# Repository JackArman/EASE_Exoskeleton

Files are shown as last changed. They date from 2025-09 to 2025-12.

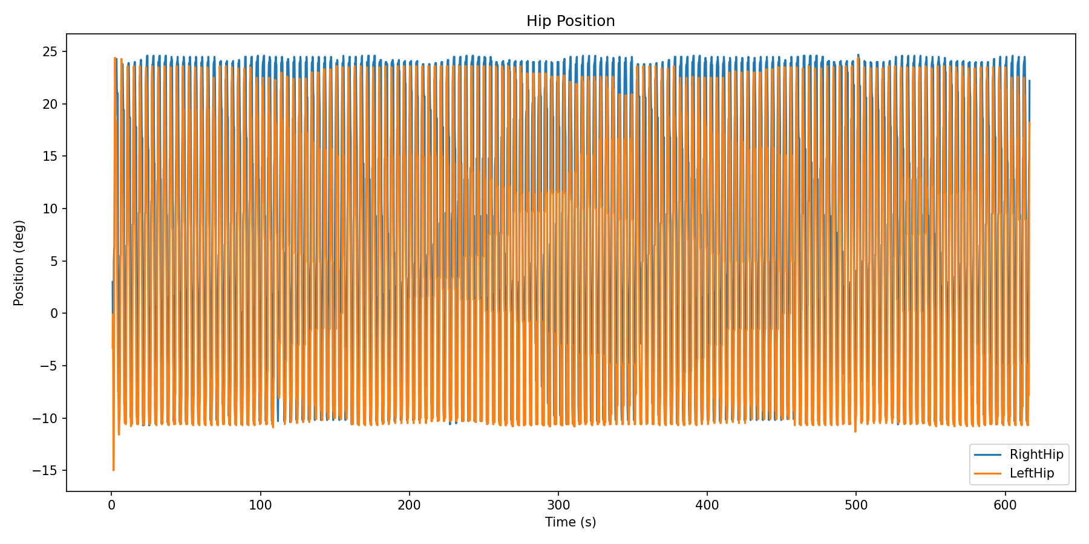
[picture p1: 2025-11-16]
Power Systems/Experiment Reults/ExperimentTest/Hip_PositionDeg.png

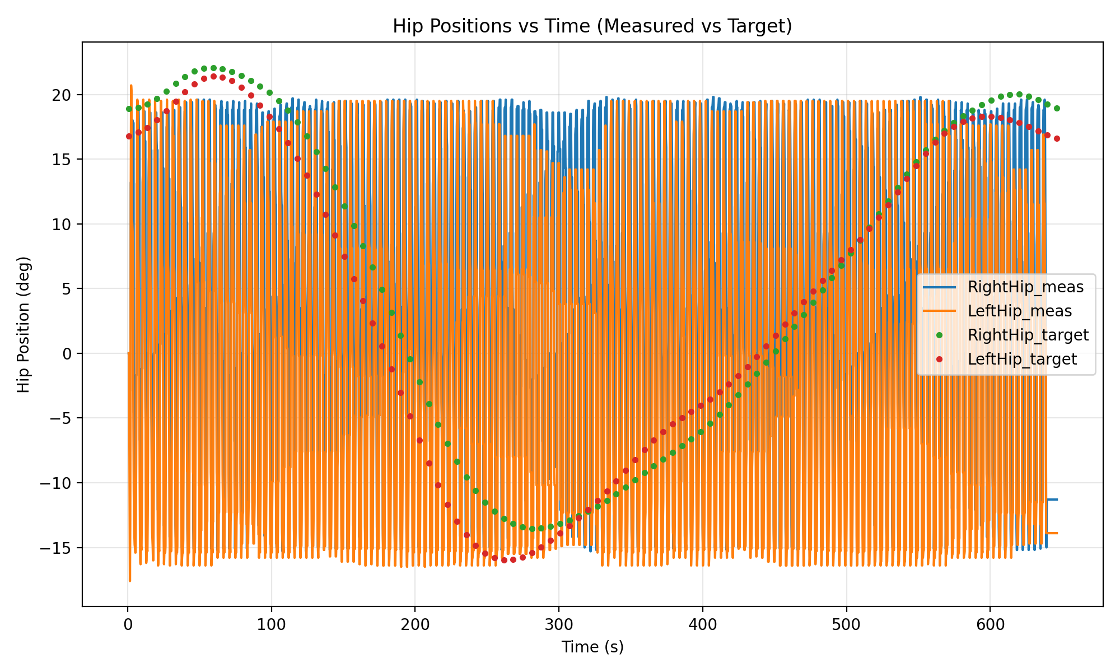
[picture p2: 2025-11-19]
Power Systems/Experiment Reults/hip_positions_with_targets.png

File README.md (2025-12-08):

# EASE – Exoskeleton for Assistive Support of Elderlies

EASE is a modular, lightweight, and energy-efficient lower-limb exoskeleton designed to support mobility in elderly individuals. This repository contains resources for the development, control, simulation, and power management systems of the EASE exoskeleton.

---

## Repository Structure
PowerSystems/ # Battery, buck converters, energy management
ControlSystems/ # Gait detection, motor control, safety features
Simulation/ # Gait cycle simulations and performance modeling
Docs/ # Literature review, diagrams, system design documents
SharedAssets/ # CAD files, visuals, datasheets

---

## Features

- Real-time energy management and fault detection
- Modular 3D-printed design for low cost and ease of maintenance
- Adaptive control strategies for various gait patterns
- Support for simulation and hardware-in-the-loop testing

---

## Related Resources

- [Google Drive Folder](https://drive.google.com/drive/folders/12fcUsN3FNqKwQU3XB_L2-6pgEOXsACwc?usp=sharing)
- [Quantitative Data](https://unsw.sharepoint.com/:x:/r/sites/EASEExoskeletonforAssistiveSupportofElderlies/_layouts/15/Doc2.aspx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)
- [Safe Work Procedure](https://salus.unsw.edu.au/unsw/#/view/Published-Safe-Work-Procedure/SWP-0009450) 
---

## Documentation

Refer to the [`Docs/`](./Docs/) folder for:
- System architecture diagrams
- Literature reviews
- Regulatory considerations
- Evaluation methodology

### Control Systems Documentation

Refer to the README.md within [Control System/README.md](Control%20System/README.md)

### Mechanical Systems Documentation

Refer to the README.md within [Mechanical System/README.md](Mechanical%20System/README.md)

---

## Contributors

- Power Systems Team
- Control Systems Team
- Simulation & Modelling Team

---

## License

This project is licensed under the UNSW License.

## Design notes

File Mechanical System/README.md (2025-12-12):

# EASE Exoskeleton – Mechanical System
The Mechanical System can be further divided into the **Exoskeleton's Docking Station** and **Exoskeleton's Back and Arm rests**. The docking station was made on Fusion360 whilst (majority of) the back and arm rest was made on Solidworks.

## ⚙ Docking Station
### Description
The docking station consists of 3D printed parts custom-designed to the current backrest and is held by a frame made out of 40 x 40 20 series V-slot extrusions. It is design for easy use so the elderly walks forwards into it.
Please see the video to demonstrate how it works.

The following is a list of all files and descriptions:

`ASSEMBLY - Full Assembly` - This is an full exoskeleton assembly with the original leg assembly but uses an outdated back and arm rest assembly.

`Armrest motor mount` - The current adaptor between the original leg design and the arm rests, however, this has been prone to shearing at a 15% infill.

`Docking Station Assembly` - A one sided assembly of the Docking Station showing the location of armrest, hinge, stopping mechanism and shape of frame.

`Docking Station Arm` - Arms that extend from the under the armrest to the backrest to support the backrest weight and ensure the exoskeleton's U-joint does not rotate and cause the exoskeleton to fall off. Has a section cut off from it for the weight based locking mechanism. 
Two springs are to be situate in the small circle cut outs and when exoskeleton rest upon it, the piece's extrusion at the bottom hits the stopper, preventing the hinge to return to its original position.

`Ramp fitting` - Ramp to stop the hinge from overturning.

`Returning Hinge` - Inaccurate CAD of TruClose® Self-Closing Pool Gate Safety Hinges but with joint added for demonstration.

`Spring Stopper` - Attachment to pole that works with the spring system on the `Docking Station Arm`s to stop the hinge from returning when exoskeleton is on it.

`Vslot Corner joint` - The joint that is used to construct the Vslot frame.
### Recommended improvements
- Redesign or reprint a stronger `armrest motor mount`
- Stronger joint design to restict the frame's vertical poles more
- Design stopping mechanism so the hinge does not over or under turn when returning to original position, currently the ramp has this job but needs constant tuning
- Design an physical indicator when the elderly should stop walking into the docking station and unstrap
- Current design has a 20 x 40 Rectangular Pole running in the middle - a tripping hazard for elderly

## 💪 Back and Arm rests

### Description
The Back and Arm rests is a complicated system featuring multiple 3D printed components and a U joint to cater for the flexibility of a humans' hip joint.

The following is a list of all files and descriptions:

`Armrest Front Section L and R` - The front section of the armrest with cut out for potentiometer and emergency stop. Also potentiometer knob and visual dial.

### Recommended improvements
- Add padding on the backrests for more comfort
- Better strap design as current design has some slipping, maybe strap to shoulders
- Better design so exoskeleton legs are closer to elderly's legs
# General advice
- Have a good plan at the start of every term to keep track of progress and outline dependancies
- Have a agreed method of sharing files (like using this repositry or through Fusion's shared project spaces)
- Good communication between design teams so integration is easy
- Design with manufacturing process in mind (size of design, assembly, fasteners, manufacturing time)

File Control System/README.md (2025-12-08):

# EASE Exoskeleton – MIT Position Control System

This project controls a powered lower-limb exoskeleton using a predefined gait pattern and a CAN-based MIT motor control protocol.  
It runs on an ESP32 with an MCP2515 CAN controller and drives four motors:

- Left Hip  
- Left Knee  
- Right Hip  
- Right Knee  

The system is designed for research and educational use.

---

## 🧠 Project Idea

The goal of this project is to simulate human walking (gait) by:

- Using prerecorded joint angle trajectories  
- Sending real-time motor commands over the CAN bus  
- Synchronising hip and knee movement  
- Allowing the user to control walking speed using a dial (potentiometer)  

This project enables work in:

- Gait research  
- Lower-limb exoskeleton control  
- Rehabilitation system prototyping  

---

## ⚙️ How the System Works

### Gait Trajectories

The system uses four lookup tables:

- `L_hip[]`  
- `L_knee[]`  
- `R_hip[]`  
- `R_knee[]`  

Each array contains 100 position values that represent one full walking step for each joint.

### Control Loop

The controller continuously:

1. Reads the current gait index  
2. Looks up the target joint angles  
3. Converts values into MIT motor protocol commands  
4. Sends the commands over the CAN bus  

This produces smooth and continuous walking motion.

### Speed Control Dial

A potentiometer (dial) connected to the ESP32 controls walking speed:

| Dial Position | Behaviour |
|---|---|
| Low | Slow walking |
| Medium | Normal walking |
| High | Fast walking |
| Off | Stops motion |

Note: 
  - The potentiometer also acts as the off switch for the exoskelton
  - The current code forces `DIAL_MEDIUM` for testing purposes.

### Soft Start Movement

When the system starts, the legs are slowly moved into the initial gait position to avoid sudden or unsafe motion.

---

## 🪛 Hardware Requirements

- ESP32 development board  
- MCP2515 CAN controller  
- CAN transceiver module  
- 4 × Cubemars motors  
- RUBIK LINK V3.0 interface board  
- Potentiometer (speed control dial)  
- 24V power supply suitable for the motors  

---

## 🔌 How to Physically Connect the System (Test Setup)

Motor LED indicators:

- **Blue LED** → Power is available and the motor is ready for testing  
- **Red LED** → Hardware fault detected. It is recommended to stop and check the motor manual  

To run trial simulations using the CubeMars software:

1. Connect the **Cubemars motors** to an appropriate power supply  
2. Connect the motors to the **RUBIK LINK V3.0** board and connect the RUBIK LINK V3.0 to your laptop  
   - The RUBIK LINK V3.0 can also be used to reset the Motor ID if required  
3. Use the CubeMars software to test (INSERT LINK):
   - Velocity  
   - Power  
   - Torque  

Note: Depending on your laptop configuration, you may need to install additional USB or serial drivers so that your computer can detect the ESP32 correctly.

---

## 🧾 How to Upload the Code and Test (Arduino IDE)

## 📦 Required Libraries (IMPORTANT FOR STUDENTS)

Important: Students must install the MCP2515 library before the code will compile.

The required ZIP file is located in:

Control System/MIT_position_control/Arduino MCP2515 Library.zip

### Setup and Upload Steps

1. Connect the motors to the required **24V power supply**  
2. Ensure the ESP32 board is correctly connected to:
   - The MCP2515 CAN module  
   - The motor CAN wiring  
3. Connect the ESP32 board to your laptop using a **USB-C cable**  
4. Open **Arduino IDE**  
5. Select:
   - Board: `ESP32 Dev Module`  
   - The correct COM/Serial Port  

   Note: Depending on laptop configuration, some students may need to install additional drivers to allow the laptop to detect the ESP32 as a serial device.

6. Click **Upload** in Arduino IDE to flash the code to the ESP32  

Once uploaded, the motors will begin running the code

---

## 📊 Serial Monitoring (Optional)

The system can output real-time data over the Serial Monitor.

Recommended settings:

- Baud rate: `921600`  

Data includes gait step indices and raw motor feedback for debugging and analysis.

---

## ⚠️ Safety Notice

This system controls high-power motors.

Do NOT:

- Run the system while being worn  
- Touch moving parts while powered  
- Operate without supervision  

Always use physical safety stops and testing rigs when experimenting.

This system is for **research and educational use only**.

---

## 🚀 Future Work

The EASE Exoskeleton team plans several improvements and expansions to the current system to enhance performance, maintainability, and research capabilities:

### 1. Refactor to State Machine Architecture
- Currently, the gait control loop is a **linear data-driven loop**, which makes it harder to extend and maintain.
- Future versions will use **object-oriented programming and state machines**:
  - Separate classes for each phase of gait (e.g., stance, swing, recovery)
  - Each class will handle its own motor commands, timing, and transitions
  - This will make the system **modular, easier to debug, and extendable** for more complex gait patterns

### 2. Adaptive Control
- Implement **adaptive or feedback-based control** to allow the exoskeleton to respond to:
  - Variations in user weight and gait speed
  - Changes in terrain or resistance
  - Motor performance or wear over time
- This could include closed-loop PID gains that automatically adjust based on sensor feedback or user input

### 3. Enhanced Safety Features
- Introduce **automatic emergency stops** if torque, velocity, or position limits are exceeded
- Add **real-time monitoring** of joint temperatures, currents, and motor health
- Improve **soft-start and soft-stop routines** to reduce mechanical stress and risk to users

### 4. Expanded Hardware Integration
- Add support for **additional sensors**, such as:
  - IMUs for detecting limb orientation
  - Force sensors under the foot to detect load and stance phase
- Allow **wireless telemetry** for remote monitoring and data logging

### 5. Data Logging and Analysis
- Improve logging format for better post-processing
- Implement **live visualization tools** to observe gait patterns and motor states in real time
- Enable **export of gait data** for research and comparison

### 6. User Customization
- Provide a **calibration routine** for different users
- Allow dynamic adjustment of gait speed, step length, and torque limits
- Include a **graphical user interface (GUI)** for simplified testing and control

### 7. Digital Twin and User Modeling

- Develop a **digital twin** of the exoskeleton and the user’s lower limbs:
  - Simulate joint positions, velocities, torques, and gait patterns in software
  - Mirror the physical system in real-time to analyze performance and predict mechanical stress
- Use **sensor data** (IMUs, force sensors, encoders) to update the digital twin:
  - Track the user’s actual walking motion
  - Compare intended gait trajectory vs. real user motion
  - Adjust motor commands dynamically for improved assistance and safety
- Enable **personalized gait adaptation**:
  - The system can learn each user’s walking style
  - Adjust torque, step length, and timing for maximum comfort and efficiency
- Facilitate **research and testing**:
  - Run simulations to test new gait algorithms without risking the physical hardware
  - Collect data for rehabilitation studies or machine learning models

These improvements will make the exoskeleton system more robust, adaptable, and suitable for both research and real-world prototyping.

---
## 👨‍💻 Project Information

EASE Exoskeleton Project  
ESP32 + MCP2515 + MIT Motor Protocol

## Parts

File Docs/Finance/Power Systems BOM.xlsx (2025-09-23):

Item # | Description | Vendor | Part Number | Qty | Unit Price (AUD) | Cost (AUD) | Link to Where to Purchase | Notes | Progress
1 | Active Balancing BMS | AliExpress (JiKong) | JK-BD6A24S10P | 1 | $128.41 | $128.41 | https://www.aliexpress.com/item/1005008042959707.html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 | Has to be this for active balancing | In Progress
2 | Blade Fuse Holder | Altronics | S6036 | 5 | $2.95 | $14.75 | https://www.altronics.com.au/p/s6036-30a-in-line-blade-fuse-holder/ |  | In Progress
3 | CAN Bus Module | Amazon | MCP2515 | 2 | $18.19 | $36.38 | https://www.amazon.com.au/LT-Easiyl-Industrial-Monitoring-Accessories/dp/B0CR1F4P1G?s=electronics | *Can delete* | Unneeded
4 | Battery Isolator Switch | Amazon |  | 2 | $18.89 | $37.78 | https://www.amazon.com.au/Telsitine-Battery-Disconnect-12V-48V-Isolator/dp/B0BW3R23CX
5 | Estop Switch | JayCar | SP0786 | 2 | $21.95 | $43.90 | https://www.jaycar.com.au/latching-emergency-stop-switch/p/SP0786?gStoreCode=911
6 | Blade Fuse 25A | JayCar | SF2137 | 5 | $1.10 | $5.50 | https://www.jaycar.com.au/25a-clear-standard-blade-fuse/p/SF2137?gStoreCode=911
7 | LM1086 5-3.3v LDO | Mouser | LM1086CT-3.3/NOPB | 6 | $3.30 | $19.80 | https://au.mouser.com/ProductDetail/Texas-Instruments/LM1086CT-3.3-NOPB?qs=X1J7HmVL2ZFzwLoEFpqMXw%3D%3D |  | Done
8 | 10C/W Heatsink | Mouser | 590102B03600G | 5 | $2.36 | $11.80 | https://au.mouser.com/ProductDetail/Aavid/590102B03600G?qs=93uzuGORGqdUdvW3f8fnpQ%3D%3D |  | Done
9 | Heatsink Mount | Mouser | 4880SG | 3 | $7.49 | $22.47 | https://au.mouser.com/ProductDetail/Aavid/4880SG?qs=MnLw5eI5rfiaN93%2F8XQqcQ%3D%3D |  | Done
10 | PCB Manufacturing | PCBWAY |  | 5 |  | $102.00 | https://jlcpcb.com/ | Shipping: ~$50 | Done
11 | ESP32 Board | Rapid Robotics Australia | ESP32 | 4 | $11.95 | $47.80 | https://rapidroboticsaustralia.com/products/esp32-main-board-with-wi-fi-and-bluetooth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 | Shipping: ~$10 | Unneeded
12 | 18650 Samsung 30Q 3000mAh Batteries | TinkerTech | INR18650 30Q | 50 | $7.19 | $359.50 | https://www.tinkertechau.com.au/products/samsung-30q |  | In Progress
 |  |  |  |  |  | $0.00 |  |  | Unneeded
 |  |  |  |  |  | $0.00 |  |  | Unneeded
 |  |  |  |  | Total | $830.09

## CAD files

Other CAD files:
Mechanical System/Back and Arm Rests/Armrest - Front section L and R.f3z
Mechanical System/Docking Station/Vslot Corner Joint.f3d

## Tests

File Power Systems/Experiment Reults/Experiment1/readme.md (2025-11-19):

faults: - plug disconnected during use on right motor hip. logged 3 mins successfully, restart at 7 mins left

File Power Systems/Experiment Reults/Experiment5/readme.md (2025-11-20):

-warning cell undervoltage.
-stop cell undervoltage.

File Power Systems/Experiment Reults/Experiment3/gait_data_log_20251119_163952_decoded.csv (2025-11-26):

TimeStep | Elapsed_us | L_Gait_Index | R_Gait_Index | RightHip_pos_deg | RightHip_spd_eRPM | RightHip_spd_mech_RPM | RightHip_current_A | RightHip_temp_C | RightHip_err_code | RightHip_err_text | RightKnee_pos_deg | RightKnee_spd_eRPM | RightKnee_spd_mech_RPM | RightKnee_current_A | RightKnee_temp_C | RightKnee_err_code | RightKnee_err_text | LeftKnee_pos_deg | LeftKnee_spd_eRPM | LeftKnee_spd_mech_RPM | LeftKnee_current_A | LeftKnee_temp_C | LeftKnee_err_code | LeftKnee_err_text | LeftHip_pos_deg | LeftHip_spd_eRPM | LeftHip_spd_mech_RPM | LeftHip_current_A | LeftHip_temp_C | LeftHip_err_code | LeftHip_err_text
0 | 718940 | 1 | 51 | 0.0 | 0.0 | 0.0 | 0.0 | 0 | 0 | OK | 0.0 | 0.0 | 0.0 | 0.0 | 0 | 0 | OK | 0.0 | 0.0 | 0.0 | 0.0 | 0 | 0 | OK | 0.0 | 0.0 | 0.0 | 0.0 | 0 | 0 | OK
5 | 919885 | 6 | 56 | 0.0 | 0.0 | 0.0 | 0.0 | 0 | 0 | OK | 0.0 | 0.0 | 0.0 | 0.0 | 0 | 0 | OK | 0.0 | 0.0 | 0.0 | 0.0 | 0 | 0 | OK | 0.0 | 0.0 | 0.0 | 0.0 | 0 | 0 | OK
10 | 1120885 | 11 | 61 | 0.0 | 0.0 | 0.0 | 0.0 | 0 | 0 | OK | 0.0 | 0.0 | 0.0 | 0.0 | 0 | 0 | OK | 0.0 | 0.0 | 0.0 | 0.0 | 0 | 0 | OK | 0.0 | 0.0 | 0.0 | 0.0 | 0 | 0 | OK
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

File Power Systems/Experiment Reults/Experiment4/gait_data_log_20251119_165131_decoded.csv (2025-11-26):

TimeStep | Elapsed_us | L_Gait_Index | R_Gait_Index | RightHip_pos_deg | RightHip_spd_eRPM | RightHip_spd_mech_RPM | RightHip_current_A | RightHip_temp_C | RightHip_err_code | RightHip_err_text | RightKnee_pos_deg | RightKnee_spd_eRPM | RightKnee_spd_mech_RPM | RightKnee_current_A | RightKnee_temp_C | RightKnee_err_code | RightKnee_err_text | LeftKnee_pos_deg | LeftKnee_spd_eRPM | LeftKnee_spd_mech_RPM | LeftKnee_current_A | LeftKnee_temp_C | LeftKnee_err_code | LeftKnee_err_text | LeftHip_pos_deg | LeftHip_spd_eRPM | LeftHip_spd_mech_RPM | LeftHip_current_A | LeftHip_temp_C | LeftHip_err_code | LeftHip_err_text
0 | 718941 | 1 | 51 | 0.0 | 0.0 | 0.0 | 0.0 | 0 | 0 | OK | 0.0 | 0.0 | 0.0 | 0.0 | 0 | 0 | OK | 0.0 | 0.0 | 0.0 | 0.0 | 0 | 0 | OK | 0.0 | 0.0 | 0.0 | 0.0 | 0 | 0 | OK
5 | 919886 | 6 | 56 | 0.0 | 0.0 | 0.0 | 0.0 | 0 | 0 | OK | 0.0 | 0.0 | 0.0 | 0.0 | 0 | 0 | OK | 0.0 | 0.0 | 0.0 | 0.0 | 0 | 0 | OK | 0.0 | 0.0 | 0.0 | 0.0 | 0 | 0 | OK
10 | 1120886 | 11 | 61 | 0.0 | 0.0 | 0.0 | 0.0 | 0 | 0 | OK | 0.0 | 0.0 | 0.0 | 0.0 | 0 | 0 | OK | 0.0 | 0.0 | 0.0 | 0.0 | 0 | 0 | OK | 0.0 | 0.0 | 0.0 | 0.0 | 0 | 0 | OK
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

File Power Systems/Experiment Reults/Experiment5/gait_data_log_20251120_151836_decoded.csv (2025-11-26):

TimeStep | Elapsed_us | L_Gait_Index | R_Gait_Index | RightHip_pos_deg | RightHip_spd_eRPM | RightHip_spd_mech_RPM | RightHip_current_A | RightHip_temp_C | RightHip_err_code | RightHip_err_text | RightKnee_pos_deg | RightKnee_spd_eRPM | RightKnee_spd_mech_RPM | RightKnee_current_A | RightKnee_temp_C | RightKnee_err_code | RightKnee_err_text | LeftKnee_pos_deg | LeftKnee_spd_eRPM | LeftKnee_spd_mech_RPM | LeftKnee_current_A | LeftKnee_temp_C | LeftKnee_err_code | LeftKnee_err_text | LeftHip_pos_deg | LeftHip_spd_eRPM | LeftHip_spd_mech_RPM | LeftHip_current_A | LeftHip_temp_C | LeftHip_err_code | LeftHip_err_text
0 | 10011355 | 0 | 50 | 0.0 | 0.0 | 0.0 | 0.0 | 0 | 0 | OK | -128.5 | -7710.0 | -367.143 | -6.41 | -9 | 255 | Unknown(255) | 0.0 | 0.0 | 0.0 | 0.0 | 0 | 0 | OK | -128.5 | -7710.0 | -367.143 | -6.41 | -9 | 255 | Unknown(255)
5 | 10022728 | 0 | 50 | -0.2 | 0.0 | 0.0 | -0.04 | 30 | 0 | OK | 3.0 | -10.0 | -0.476 | 0.56 | 26 | 0 | OK | -2.0 | 10.0 | 0.476 | 0.39 | 26 | 0 | OK | 0.1 | 0.0 | 0.0 | -0.05 | 29 | 0 | OK
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

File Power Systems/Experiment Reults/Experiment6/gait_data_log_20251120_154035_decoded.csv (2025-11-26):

TimeStep | Elapsed_us | L_Gait_Index | R_Gait_Index | RightHip_pos_deg | RightHip_spd_eRPM | RightHip_spd_mech_RPM | RightHip_current_A | RightHip_temp_C | RightHip_err_code | RightHip_err_text | RightKnee_pos_deg | RightKnee_spd_eRPM | RightKnee_spd_mech_RPM | RightKnee_current_A | RightKnee_temp_C | RightKnee_err_code | RightKnee_err_text | LeftKnee_pos_deg | LeftKnee_spd_eRPM | LeftKnee_spd_mech_RPM | LeftKnee_current_A | LeftKnee_temp_C | LeftKnee_err_code | LeftKnee_err_text | LeftHip_pos_deg | LeftHip_spd_eRPM | LeftHip_spd_mech_RPM | LeftHip_current_A | LeftHip_temp_C | LeftHip_err_code | LeftHip_err_text
0 | 10011348 | 0 | 50 | 0.0 | 0.0 | 0.0 | 0.0 | 0 | 0 | OK | 0.0 | 0.0 | 0.0 | 0.0 | 0 | 0 | OK | -128.5 | -7710.0 | -367.143 | -6.41 | -9 | 255 | Unknown(255) | -128.5 | -7710.0 | -367.143 | -6.41 | -9 | 255 | Unknown(255)
5 | 10022728 | 0 | 50 | 0.4 | -10.0 | -0.476 | 0.13 | 30 | 0 | OK | 0.3 | 0.0 | 0.0 | -0.07 | 26 | 0 | OK | -0.1 | 0.0 | 0.0 | -0.01 | 26 | 0 | OK | 0.0 | 0.0 | 0.0 | -0.09 | 28 | 0 | OK
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

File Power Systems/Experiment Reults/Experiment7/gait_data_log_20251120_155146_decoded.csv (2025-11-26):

TimeStep | Elapsed_us | L_Gait_Index | R_Gait_Index | RightHip_pos_deg | RightHip_spd_eRPM | RightHip_spd_mech_RPM | RightHip_current_A | RightHip_temp_C | RightHip_err_code | RightHip_err_text | RightKnee_pos_deg | RightKnee_spd_eRPM | RightKnee_spd_mech_RPM | RightKnee_current_A | RightKnee_temp_C | RightKnee_err_code | RightKnee_err_text | LeftKnee_pos_deg | LeftKnee_spd_eRPM | LeftKnee_spd_mech_RPM | LeftKnee_current_A | LeftKnee_temp_C | LeftKnee_err_code | LeftKnee_err_text | LeftHip_pos_deg | LeftHip_spd_eRPM | LeftHip_spd_mech_RPM | LeftHip_current_A | LeftHip_temp_C | LeftHip_err_code | LeftHip_err_text
0 | 10011363 | 0 | 50 | 0.0 | 0.0 | 0.0 | 0.0 | 0 | 0 | OK | 0.0 | 0.0 | 0.0 | 0.0 | 0 | 0 | OK | -5.9 | 0.0 | 0.0 | 0.0 | 27 | 0 | OK | -0.1 | 0.0 | 0.0 | 0.0 | 30 | 0 | OK
5 | 10022728 | 0 | 50 | 1.8 | -10.0 | -0.476 | 0.28 | 31 | 0 | OK | 2.5 | 0.0 | 0.0 | 0.4 | 27 | 0 | OK | -5.9 | 20.0 | 0.952 | 1.1 | 27 | 0 | OK | -0.1 | 0.0 | 0.0 | 0.06 | 31 | 0 | OK
10 | 10033832 | 0 | 50 | 1.8 | -10.0 | -0.476 | 0.28 | 31 | 0 | OK | 2.5 | 0.0 | 0.0 | 0.4 | 27 | 0 | OK | -5.9 | 20.0 | 0.952 | 1.1 | 27 | 0 | OK | -0.1 | -10.0 | -0.476 | -0.06 | 31 | 0 | OK
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

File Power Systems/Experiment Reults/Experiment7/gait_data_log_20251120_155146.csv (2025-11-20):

TimeStep | Elapsed_us | L_Gait_Index | R_Gait_Index | RH_0 | RH_1 | RH_2 | RH_3 | RH_4 | RH_5 | RH_6 | RH_7 | RK_0 | RK_1 | RK_2 | RK_3 | RK_4 | RK_5 | RK_6 | RK_7 | LK_0 | LK_1 | LK_2 | LK_3 | LK_4 | LK_5 | LK_6 | LK_7 | LH_0 | LH_1 | LH_2 | LH_3 | LH_4 | LH_5 | LH_6 | LH_7
0 | 10011363 | 0 | 50 | 0 | 0 | 0 | 0 | 0 | 0 | 0 | 0 | 0 | 0 | 0 | 0 | 0 | 0 | 0 | 0 | 255 | 197 | 0 | 0 | 0 | 0 | 27 | 0 | 255 | 255 | 0 | 0 | 0 | 0 | 30 | 0
5 | 10022728 | 0 | 50 | 0 | 18 | 255 | 255 | 0 | 28 | 31 | 0 | 0 | 25 | 0 | 0 | 0 | 40 | 27 | 0 | 255 | 197 | 0 | 2 | 0 | 110 | 27 | 0 | 255 | 255 | 0 | 0 | 0 | 6 | 31 | 0
10 | 10033832 | 0 | 50 | 0 | 18 | 255 | 255 | 0 | 28 | 31 | 0 | 0 | 25 | 0 | 0 | 0 | 40 | 27 | 0 | 255 | 197 | 0 | 2 | 0 | 110 | 27 | 0 | 255 | 255 | 255 | 255 | 255 | 250 | 31 | 0
15 | 10044728 | 0 | 50 | 0 | 18 | 255 | 255 | 0 | 28 | 31 | 0 | 0 | 23 | 255 | 232 | 0 | 94 | 27 | 0 | 255 | 205 | 0 | 119 | 0 | 159 | 27 | 0 | 255 | 255 | 255 | 255 | 255 | 250 | 31 | 0
20 | 10055944 | 0 | 50 | 0 | 18 | 255 | 255 | 0 | 28 | 31 | 0 | 0 | 23 | 255 | 249 | 0 | 59 | 27 | 0 | 255 | 211 | 0 | 100 | 0 | 86 | 27 | 0 | 255 | 255 | 255 | 247 | 0 | 12 | 31 | 0
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

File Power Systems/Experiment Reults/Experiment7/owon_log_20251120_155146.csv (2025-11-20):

epoch_s | iso_time | value | raw
1763614306.3565545 | 2025-11-20T15:51:46.356555 | 0.1628613 | 1.628613E-01
1763614306.420901 | 2025-11-20T15:51:46.420901 | 0.1628862 | 1.628862E-01
1763614306.4576974 | 2025-11-20T15:51:46.457697 | 0.1628862 | 1.628862E-01
1763614306.5072315 | 2025-11-20T15:51:46.507231 | 0.1628862 | 1.628862E-01
1763614306.5575838 | 2025-11-20T15:51:46.557584 | 0.1628862 | 1.628862E-01
1763614306.6070428 | 2025-11-20T15:51:46.607043 | 0.1628862 | 1.628862E-01
1763614306.6580575 | 2025-11-20T15:51:46.658057 | 0.1628862 | 1.628862E-01
1763614306.7207441 | 2025-11-20T15:51:46.720744 | 0.1625766 | 1.625766E-01
1763614306.757717 | 2025-11-20T15:51:46.757717 | 0.1625766 | 1.625766E-01
1763614306.8077414 | 2025-11-20T15:51:46.807741 | 0.1625766 | 1.625766E-01
1763614306.8574162 | 2025-11-20T15:51:46.857416 | 0.1625766 | 1.625766E-01
1763614306.9073706 | 2025-11-20T15:51:46.907371 | 0.1625766 | 1.625766E-01
1763614306.9567175 | 2025-11-20T15:51:46.956717 | 0.1625766 | 1.625766E-01
1763614307.0200953 | 2025-11-20T15:51:47.020095 | 0.1629289 | 1.629289E-01
1763614307.0568478 | 2025-11-20T15:51:47.056848 | 0.1629289 | 1.629289E-01
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

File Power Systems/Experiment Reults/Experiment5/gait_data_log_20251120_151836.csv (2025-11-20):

TimeStep | Elapsed_us | L_Gait_Index | R_Gait_Index | RH_0 | RH_1 | RH_2 | RH_3 | RH_4 | RH_5 | RH_6 | RH_7 | RK_0 | RK_1 | RK_2 | RK_3 | RK_4 | RK_5 | RK_6 | RK_7 | LK_0 | LK_1 | LK_2 | LK_3 | LK_4 | LK_5 | LK_6 | LK_7 | LH_0 | LH_1 | LH_2 | LH_3 | LH_4 | LH_5 | LH_6 | LH_7
0 | 10011355 | 0 | 50 | 0 | 0 | 0 | 0 | 0 | 0 | 0 | 0 | 250 | 251 | 252 | 253 | 253 | 127 | 247 | 255 | 0 | 0 | 0 | 0 | 0 | 0 | 0 | 0 | 250 | 251 | 252 | 253 | 253 | 127 | 247 | 255
5 | 10022728 | 0 | 50 | 255 | 254 | 0 | 0 | 255 | 252 | 30 | 0 | 0 | 30 | 255 | 255 | 0 | 56 | 26 | 0 | 255 | 236 | 0 | 1 | 0 | 39 | 26 | 0 | 0 | 1 | 0 | 0 | 255 | 251 | 29 | 0
10 | 10033834 | 0 | 50 | 255 | 254 | 0 | 0 | 255 | 252 | 30 | 0 | 0 | 30 | 255 | 255 | 0 | 56 | 26 | 0 | 255 | 236 | 0 | 1 | 0 | 39 | 26 | 0 | 0 | 1 | 255 | 255 | 0 | 29 | 29 | 0
15 | 10044728 | 0 | 50 | 255 | 254 | 0 | 0 | 255 | 252 | 30 | 0 | 0 | 26 | 255 | 193 | 0 | 41 | 27 | 0 | 255 | 237 | 0 | 38 | 0 | 38 | 27 | 0 | 0 | 1 | 255 | 255 | 0 | 29 | 29 | 0
20 | 10056053 | 0 | 50 | 255 | 254 | 0 | 0 | 255 | 253 | 30 | 0 | 0 | 24 | 255 | 218 | 0 | 57 | 27 | 0 | 255 | 239 | 0 | 19 | 0 | 62 | 27 | 0 | 0 | 1 | 255 | 254 | 0 | 51 | 29 | 0
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

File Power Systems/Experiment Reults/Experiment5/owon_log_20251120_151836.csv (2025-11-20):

epoch_s | iso_time | value | raw
1763612316.9721844 | 2025-11-20T15:18:36.972184 | 0.1529751 | 1.529751E-01
1763612317.0400102 | 2025-11-20T15:18:37.040010 | 0.1527332 | 1.527332E-01
1763612317.0723498 | 2025-11-20T15:18:37.072350 | 0.1527332 | 1.527332E-01
1763612317.1222951 | 2025-11-20T15:18:37.122295 | 0.1527332 | 1.527332E-01
1763612317.172199 | 2025-11-20T15:18:37.172199 | 0.1527332 | 1.527332E-01
1763612317.2227385 | 2025-11-20T15:18:37.222739 | 0.1527332 | 1.527332E-01
1763612317.2727466 | 2025-11-20T15:18:37.272747 | 0.1527332 | 1.527332E-01
1763612317.3393142 | 2025-11-20T15:18:37.339314 | 0.1525944 | 1.525944E-01
1763612317.3727355 | 2025-11-20T15:18:37.372736 | 0.1525944 | 1.525944E-01
1763612317.4221325 | 2025-11-20T15:18:37.422132 | 0.1525944 | 1.525944E-01
1763612317.4725184 | 2025-11-20T15:18:37.472518 | 0.1525944 | 1.525944E-01
1763612317.5225925 | 2025-11-20T15:18:37.522593 | 0.1525944 | 1.525944E-01
1763612317.5719092 | 2025-11-20T15:18:37.571909 | 0.1525944 | 1.525944E-01
1763612317.638788 | 2025-11-20T15:18:37.638788 | 0.1523595 | 1.523595E-01
1763612317.6721482 | 2025-11-20T15:18:37.672148 | 0.1523595 | 1.523595E-01
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

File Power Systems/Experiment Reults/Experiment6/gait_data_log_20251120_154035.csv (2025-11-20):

TimeStep | Elapsed_us | L_Gait_Index | R_Gait_Index | RH_0 | RH_1 | RH_2 | RH_3 | RH_4 | RH_5 | RH_6 | RH_7 | RK_0 | RK_1 | RK_2 | RK_3 | RK_4 | RK_5 | RK_6 | RK_7 | LK_0 | LK_1 | LK_2 | LK_3 | LK_4 | LK_5 | LK_6 | LK_7 | LH_0 | LH_1 | LH_2 | LH_3 | LH_4 | LH_5 | LH_6 | LH_7
0 | 10011348 | 0 | 50 | 0 | 0 | 0 | 0 | 0 | 0 | 0 | 0 | 0 | 0 | 0 | 0 | 0 | 0 | 0 | 0 | 250 | 251 | 252 | 253 | 253 | 127 | 247 | 255 | 250 | 251 | 252 | 253 | 253 | 127 | 247 | 255
5 | 10022728 | 0 | 50 | 0 | 4 | 255 | 255 | 0 | 13 | 30 | 0 | 0 | 3 | 0 | 0 | 255 | 249 | 26 | 0 | 255 | 255 | 0 | 0 | 255 | 255 | 26 | 0 | 0 | 0 | 0 | 0 | 255 | 247 | 28 | 0
10 | 10033728 | 0 | 50 | 0 | 4 | 255 | 255 | 0 | 13 | 30 | 0 | 0 | 3 | 0 | 0 | 255 | 249 | 26 | 0 | 255 | 255 | 0 | 0 | 255 | 255 | 26 | 0 | 0 | 0 | 0 | 0 | 255 | 247 | 28 | 0
15 | 10044728 | 0 | 50 | 0 | 4 | 0 | 0 | 255 | 245 | 30 | 0 | 0 | 3 | 0 | 0 | 255 | 247 | 26 | 0 | 255 | 255 | 0 | 0 | 255 | 248 | 26 | 0 | 0 | 0 | 255 | 255 | 0 | 27 | 29 | 0
20 | 10055836 | 0 | 50 | 0 | 4 | 0 | 0 | 255 | 245 | 30 | 0 | 0 | 3 | 0 | 0 | 255 | 247 | 26 | 0 | 255 | 255 | 0 | 0 | 255 | 248 | 26 | 0 | 0 | 0 | 255 | 255 | 0 | 40 | 29 | 0
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

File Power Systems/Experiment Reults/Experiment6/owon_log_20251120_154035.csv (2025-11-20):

epoch_s | iso_time | value | raw
1763613635.4674783 | 2025-11-20T15:40:35.467478 | 0.1507794 | 1.507794E-01
1763613635.5187433 | 2025-11-20T15:40:35.518743 | 0.1507794 | 1.507794E-01
1763613635.568859 | 2025-11-20T15:40:35.568859 | 0.1507794 | 1.507794E-01
1763613635.6185944 | 2025-11-20T15:40:35.618594 | 0.1507794 | 1.507794E-01
1763613635.6681483 | 2025-11-20T15:40:35.668148 | 0.1507794 | 1.507794E-01
1763613635.7376707 | 2025-11-20T15:40:35.737671 | 0.1507154 | 1.507154E-01
1763613635.76809 | 2025-11-20T15:40:35.768090 | 0.1507154 | 1.507154E-01
1763613635.818942 | 2025-11-20T15:40:35.818942 | 0.1507154 | 1.507154E-01
1763613635.8678122 | 2025-11-20T15:40:35.867812 | 0.1507154 | 1.507154E-01
1763613635.918549 | 2025-11-20T15:40:35.918549 | 0.1507154 | 1.507154E-01
1763613635.9677148 | 2025-11-20T15:40:35.967715 | 0.1507154 | 1.507154E-01
1763613636.035984 | 2025-11-20T15:40:36.035984 | 0.1499574 | 1.499574E-01
1763613636.0682693 | 2025-11-20T15:40:36.068269 | 0.1499574 | 1.499574E-01
1763613636.1185846 | 2025-11-20T15:40:36.118585 | 0.1499574 | 1.499574E-01
1763613636.1682663 | 2025-11-20T15:40:36.168266 | 0.1499574 | 1.499574E-01
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

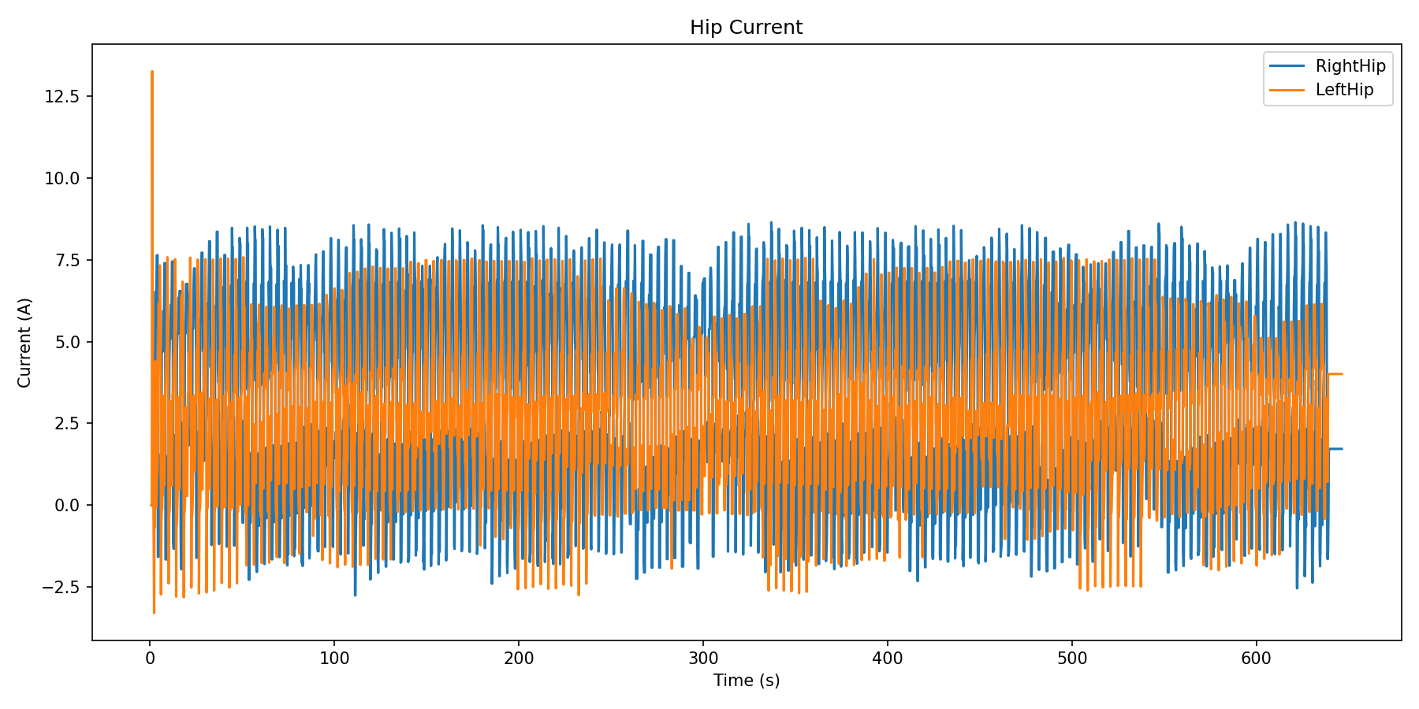
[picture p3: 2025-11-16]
Power Systems/Experiment Reults/Experiment2/Hip_CurrentA.png

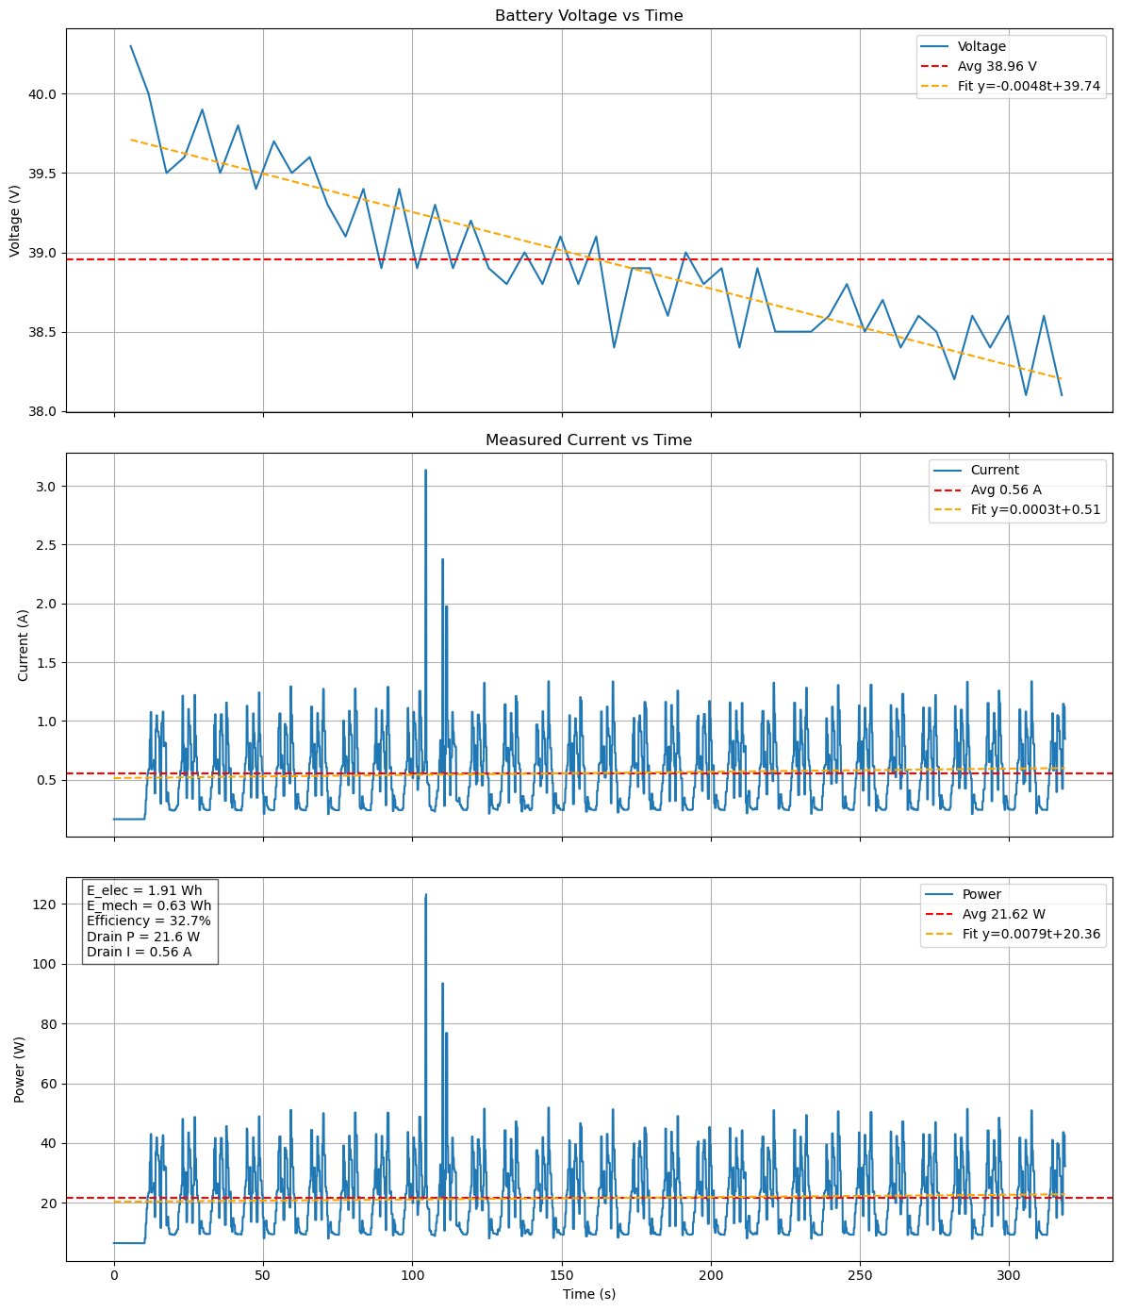
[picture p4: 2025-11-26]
Power Systems/Experiment Reults/owon7.png

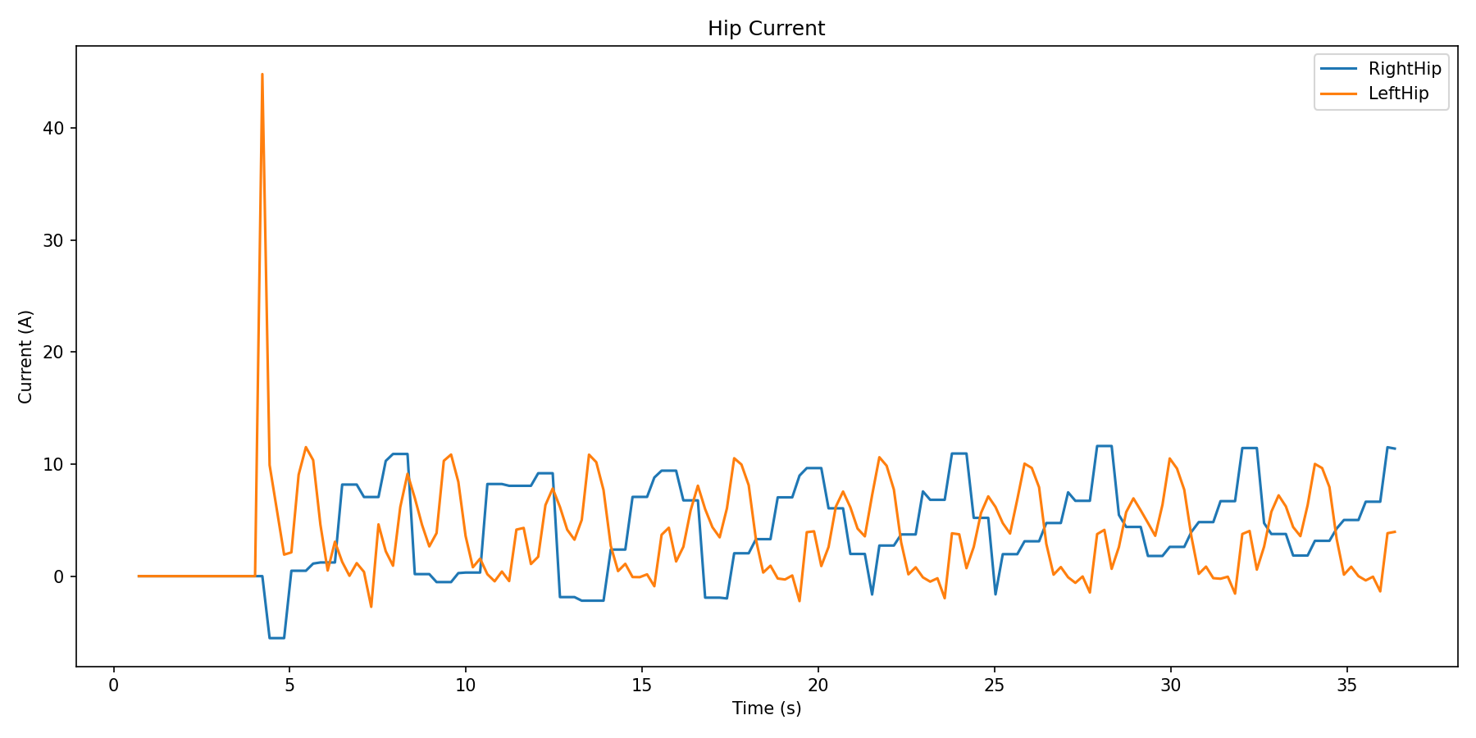
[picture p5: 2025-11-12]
Power Systems/Experiment Reults/Experiment1-2/Hip_CurrentA.png

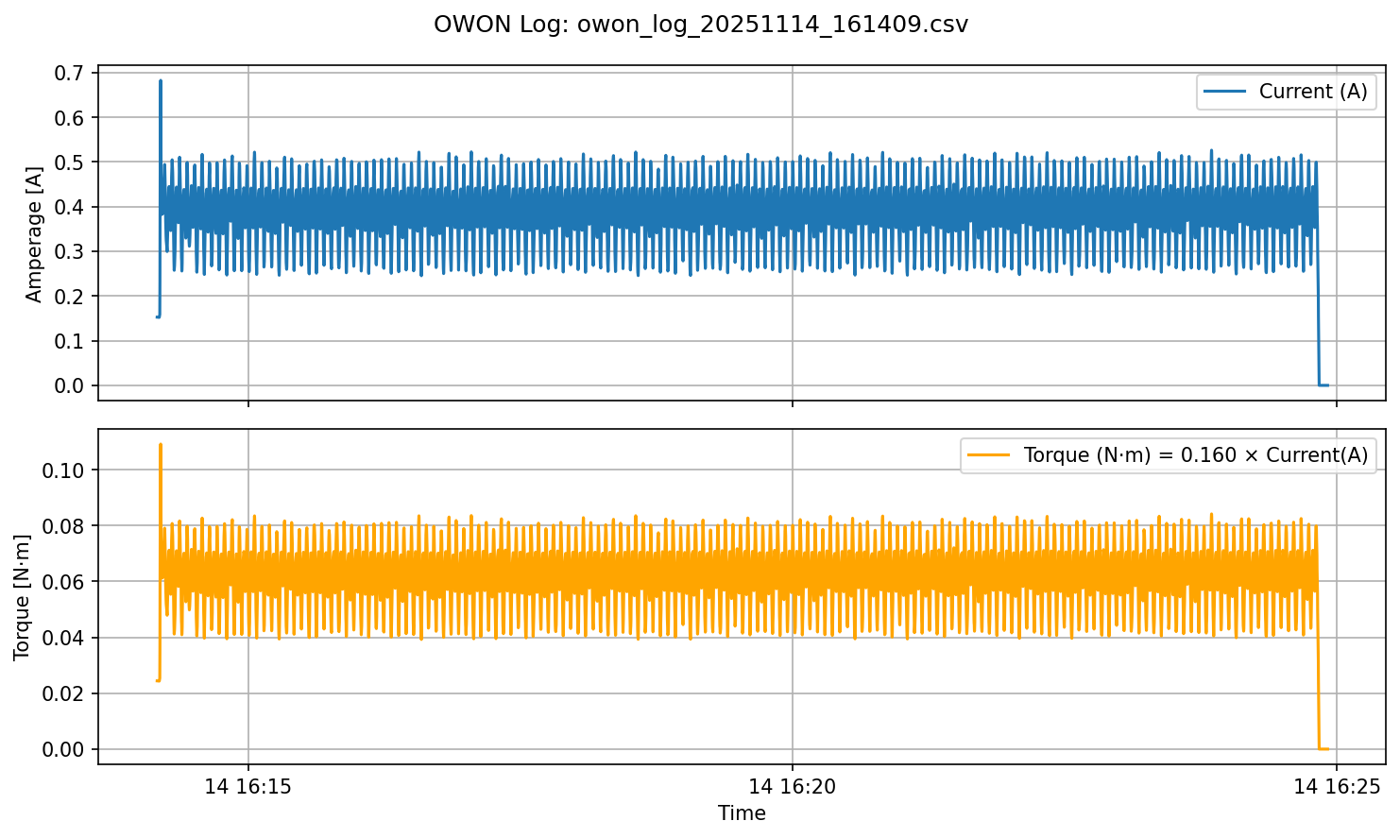
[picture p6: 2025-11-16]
Power Systems/Experiment Reults/Experiment2/owon_log_20251114_161409.png

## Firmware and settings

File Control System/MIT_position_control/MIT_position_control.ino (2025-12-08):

// =========================================================
// Exoskeleton Gait Controller — CAN + MIT Motor Protocol
// Purpose:
//   Drives 4 motors (Left/Right Hip + Knee) using
//   pre-defined gait trajectories over CAN bus.
//
// Features:
//   - Real-time gait pattern playback
//   - Dial-controlled speed (potentiometer)
//   - Feedback logging over Serial (time-stamped)
//   - Broadcast-friendly CAN RX handling
// =========================================================

#include <SPI.h>
#include <mcp2515.h>
#include <cstdint>
#include "esp_timer.h"          // High-resolution timer for ESP32

// ---------- Global CAN + Hardware Setup ----------
struct can_frame canMsg;
MCP2515 mcp2515(5);             // CAN CS pin

const int dialPin = 34;         // ADC pin for speed control dial

// Dial states map to speed delays (ms added to base delay)
enum dialState {
  DIAL_OFF = -1,    // Stop motion
  DIAL_LOW = 40,    // Slow
  DIAL_MEDIUM = 20, // Medium
  DIAL_HIGH = 0     // Fast
};

// ---------- Runtime variables ----------
double maxAmp1 = 0;
double maxAmp2 = 0;
double maxAmp3 = 0;
double maxAmp4 = 0;
double total = 0;
double maxTotal = 0;

long gait_step_counter = 0;     // Logging counter

// Latest feedback from each motor (8 bytes per motor)
uint8_t msgDataRightHip[8]  = {0};
uint8_t msgDataRightKnee[8] = {0};
uint8_t msgDataLeftHip[8]   = {0};
uint8_t msgDataLeftKnee[8]  = {0};

// Timestamp for elapsed-time logging
int64_t t0_us = 0;

// Length of gait lookup tables
#define GAIT_LENGTH 100

// =========================================================
// Gait Trajectories
// Each array represents normalized joint position over one step
// =========================================================

// Left Knee trajectory
double L_knee[GAIT_LENGTH] = {
0.042200, 0.059562, 0.092671, 0.141522, 0.204591, 0.278567, 0.358855, 0.440760, 0.520656, 0.596433,
0.667199, 0.732766, 0.793217, 0.848651, 0.899057, 0.944284, 0.984064, 1.018047, 1.045814, 1.066864,
1.080587, 1.086280, 1.083212, 1.070786, 1.048739, 1.017316, 0.977325, 0.930024, 0.876881, 0.819280,
0.758340, 0.694954, 0.630043, 0.564828, 0.500893, 0.439959, 0.383527, 0.332620, 0.287736, 0.248939,
0.215986, 0.188439, 0.165738, 0.147250, 0.132296, 0.120221, 0.110498, 0.102846, 0.097284, 0.094056,
0.093459, 0.095640, 0.100468, 0.107502, 0.116065, 0.125387, 0.134770, 0.143711, 0.151928, 0.159294,
0.165752, 0.171276, 0.175892, 0.179761, 0.183235, 0.186847, 0.191192, 0.196767, 0.203835, 0.212359,
0.222038, 0.232383, 0.242834, 0.252879, 0.262185, 0.270692, 0.278621, 0.286371, 0.294319, 0.302627,
0.311129, 0.319331, 0.326490, 0.331732, 0.334175, 0.333073, 0.327958, 0.318736, 0.305691, 0.289373,
0.270381, 0.249164, 0.225926, 0.200732, 0.173782, 0.145765, 0.118156, 0.093322, 0.074331, 0.064467
};


// Left Hip trajectory
double L_hip[GAIT_LENGTH] = {
0.292550, 0.297928, 0.304605, 0.314464, 0.326739, 0.340090, 0.352850, 0.363396, 0.370504, 0.373525,
0.372359, 0.367321, 0.358969, 0.347929, 0.334727, 0.319662, 0.302772, 0.283915, 0.262917, 0.239725,
0.214489, 0.187544, 0.159319, 0.130239, 0.100649, 0.070755, 0.040595, 0.010050, -0.021057, -0.052805,
-0.085016, -0.117162, -0.148385, -0.177646, -0.203951, -0.226550, -0.245034, -0.259313, -0.269508, -0.275855,
-0.278642, -0.278197, -0.274901, -0.269205, -0.261621, -0.252683, -0.242877, -0.232542, -0.221803, -0.210577,
-0.198666, -0.185914, -0.172330, -0.158155, -0.143842, -0.129972, -0.117101, -0.105598, -0.095527, -0.086628,
-0.078398, -0.070250, -0.061665, -0.052281, -0.041909, -0.030488, -0.018052, -0.004705, 0.009396, 0.024051,
0.039038, 0.054131, 0.069120, 0.083820, 0.098116, 0.112010, 0.125649, 0.139305, 0.153324, 0.168035,
0.183673, 0.200304, 0.217761, 0.235617, 0.253211, 0.269742, 0.284423, 0.296648, 0.306110, 0.312815,
0.317008, 0.319036, 0.319227, 0.317822, 0.314967, 0.310784, 0.305515, 0.299675, 0.294106, 0.289862
};

// Right Knee trajectory
double R_knee[GAIT_LENGTH] = {
0.037000, 0.052771, 0.084629, 0.130832, 0.188328, 0.253307, 0.322092, 0.391888, 0.461043, 0.528814,
0.594912, 0.659118, 0.721086, 0.780312, 0.836206, 0.888165, 0.935595, 0.977879, 1.014357, 1.044349,
1.067232, 1.082515, 1.089876, 1.089130, 1.080177, 1.062958, 1.037468, 1.003836, 0.962450, 0.914084,
0.859921, 0.801478, 0.740430, 0.678434, 0.616989, 0.557384, 0.500702, 0.447811, 0.399288, 0.355357,
0.315940, 0.280827, 0.249841, 0.222902, 0.199944, 0.180784, 0.165032, 0.152124, 0.141447, 0.132526,
0.125131, 0.119250, 0.114934, 0.112159, 0.110768, 0.110518, 0.111165, 0.112556, 0.114696, 0.117765,
0.122043, 0.127776, 0.135032, 0.143645, 0.153282, 0.163575, 0.174242, 0.185119, 0.196120, 0.207169,
0.218164, 0.228979, 0.239484, 0.249582, 0.259220, 0.268387, 0.277085, 0.285280, 0.292881, 0.299740,
0.305674, 0.310455, 0.313749, 0.315066, 0.313789, 0.309336, 0.301404, 0.290163, 0.276288, 0.260765,
0.244510, 0.227946, 0.210720, 0.191788, 0.169891, 0.144314, 0.115610, 0.085967, 0.059021, 0.039173
};

// Right Hip trajectory
double R_hip[GAIT_LENGTH] = {
0.330000, 0.331301, 0.335672, 0.343296, 0.353111, 0.363612, 0.373177, 0.380432, 0.384554, 0.385413,
0.383465, 0.379469, 0.374125, 0.367799, 0.360427, 0.351604, 0.340792, 0.327532, 0.311585, 0.292979,
0.271981, 0.249010, 0.224518, 0.198860, 0.172211, 0.144572, 0.115859, 0.086032, 0.055214, 0.023762,
-0.007752, -0.038644, -0.068275, -0.096169, -0.122032, -0.145656, -0.166822, -0.185285, -0.200851, -0.213446,
-0.223136, -0.230068, -0.234403, -0.236298, -0.235952, -0.233664, -0.229848, -0.224949, -0.219312, -0.213080,
-0.206199, -0.198526, -0.189985, -0.180683, -0.170927, -0.161121, -0.151609, -0.142530, -0.133761, -0.124958,
-0.115683, -0.105567, -0.094431, -0.082317, -0.069412, -0.055917, -0.041935, -0.027455, -0.012408, 0.003225,
0.019357, 0.035805, 0.052363, 0.068890, 0.085359, 0.101854, 0.118501, 0.135401, 0.152584, 0.170029,
0.187704, 0.205571, 0.223518, 0.241274, 0.258375, 0.274250, 0.288403, 0.300598, 0.310954, 0.319869,
0.327803, 0.335008, 0.341347, 0.346295, 0.349147, 0.349355, 0.346828, 0.342093, 0.336243, 0.330710
};

// Phase offset between legs (degrees-ish)
int offset = 90;

// ---------- Unique motor IDs ----------
const uint8_t MOTOR_ID_LEFT_HIP  = 0x03;
const uint8_t MOTOR_ID_RIGHT_HIP = 0x01;
const uint8_t MOTOR_ID_LEFT_KNEE = 0x04;
const uint8_t MOTOR_ID_RIGHT_KNEE= 0x02;

// =========================================================
// Helper: Convert float to fixed-width unsigned int
// Used to pack MIT motor protocol fields
// =========================================================
static inline int float_to_uint(float x, float x_min, float x_max, unsigned int bits) {
  float span = x_max - x_min;
  if (x < x_min) x = x_min;
  if (x > x_max) x = x_max;
  return (int)((x - x_min) * ((float)((1u << bits) - 1u) / span));
}

// =========================================================
// Drain CAN RX buffer for a short time window
// Purpose: avoid bus congestion and keep latest motor data
// =========================================================
static inline void drainRXUntil(uint32_t time_us) {
  const uint32_t t0 = micros();
  while (mcp2515.readMessage(&canMsg) == MCP2515::ERROR_OK) {
    uint8_t motor_id = (uint8_t)(canMsg.can_id & 0xFF);

    if (motor_id == MOTOR_ID_RIGHT_HIP)       memcpy(msgDataRightHip,  canMsg.data, 8);
    else if (motor_id == MOTOR_ID_RIGHT_KNEE) memcpy(msgDataRightKnee, canMsg.data, 8);
    else if (motor_id == MOTOR_ID_LEFT_KNEE)  memcpy(msgDataLeftKnee,  canMsg.data, 8);
    else if (motor_id == MOTOR_ID_LEFT_HIP)   memcpy(msgDataLeftHip,   canMsg.data, 8);

    if ((micros() - t0) >= time_us) break;
  }
}

// =========================================================
// Open CAN filters to accept all traffic (broadcast mode)
// =========================================================
static inline void openAllFiltersAndRollover() {
  mcp2515.setFilterMask(MCP2515::MASK0, true, 0x00000000);
  mcp2515.setFilterMask(MCP2515::MASK1, true, 0x00000000);

  mcp2515.setFilter(MCP2515::RXF0, true, 0x00000000);
  mcp2515.setFilter(MCP2515::RXF1, true, 0x00000000);
  mcp2515.setFilter(MCP2515::RXF2, true, 0x00000000);
  mcp2515.setFilter(MCP2515::RXF3, true, 0x00000000);
  mcp2515.setFilter(MCP2515::RXF4, true, 0x00000000);
  mcp2515.setFilter(MCP2515::RXF5, true, 0x00000000);
}

// =========================================================
// Send command using MIT motor protocol over CAN
// Controls:
//   - position
//   - velocity
//   - kp, kd
//   - feed-forward torque
// =========================================================
static inline void sendMITCommand(float p_des, float v_des, float kp, float kd, float t_ff, uint8_t motor_id) {
  int p_int  = float_to_uint(p_des, -12.56f, 12.56f, 16);
  int v_int  = float_to_uint(v_des, -33.0f, 33.0f, 12);
  int kp_int = float_to_uint(kp, 0.0f, 500.0f, 12);
  int kd_int = float_to_uint(kd, 0.0f, 5.0f,   12);
  int t_int  = float_to_uint(t_ff, -54.0f, 54.0f, 12);

  const uint32_t can_id = ((uint32_t)0x08 << 8) | motor_id;
  canMsg.can_id  = 0x80000000UL | can_id;   // Extended frame
  canMsg.can_dlc = 8;

  canMsg.data[0] = kp_int >> 4;
  canMsg.data[1] = ((kp_int & 0xF) << 4) | (kd_int >> 8);
  canMsg.data[2] = kd_int & 0xFF;
  canMsg.data[3] = p_int >> 8;
  canMsg.data[4] = p_int & 0xFF;
  canMsg.data[5] = v_int >> 4;
  canMsg.data[6] = ((v_int & 0xF) << 4) | (t_int >> 8);
  canMsg.data[7] = t_int & 0xFF;

  mcp2515.sendMessage(&canMsg);
}

// =========================================================
// Setup() — Runs once on boot
// =========================================================
void setup() {
  Serial.begin(921600);
  SPI.begin();

  mcp2515.reset();
  mcp2515.setBitrate(CAN_1000KBPS, MCP_8MHZ);
  openAllFiltersAndRollover();
  mcp2515.setNormalMode();

  t0_us = esp_timer_get_time();   // Start time for logs

  delay(500);
  Serial.println("Multi-joint gait tracking started");
}

// =========================================================
// Convert dial ADC value to speed state
// =========================================================
dialState getDialState(int dialValue) {
  int dialPercent = map(dialValue, 0, 4095, 0, 100);

  if (dialPercent < 25)  return DIAL_OFF;
  if (dialPercent < 50)  return DIAL_LOW;
  if (dialPercent < 75)  return DIAL_MEDIUM;
  return DIAL_HIGH;
}

// =========================================================
// Main control loop
// =========================================================
void loop() {

  // ---- Control constants ----
  const float v_des = 0.0f;
  const float kp = 40.0f;
  const float kd = 2.0f;

  const float torque_ff_max_hip = 8.71875f;
  const float torque_ff_max_knee = 4.98375f;

  // Initial gait indices (left and right legs out of phase)
  int LgaitIndex = 0;
  int RgaitIndex = GAIT_LENGTH / 2;

  // ---- Ramp torque for soft start ----
  float rampFactor = (float)LgaitIndex / 100.0;
  if (rampFactor > 1.0) rampFactor = 1.0;
  if (rampFactor < 0.0) rampFactor = 0.0;

  float torque_ff_L_HIP  = torque_ff_max_hip  * rampFactor;
  float torque_ff_L_KNEE = torque_ff_max_knee * rampFactor;

  rampFactor = (float)RgaitIndex / 100.0;

  float torque_ff_R_HIP  = torque_ff_max_hip  * rampFactor;
  float torque_ff_R_KNEE = torque_ff_max_knee * rampFactor;

  delay(10);

  // Read dial speed control
  int dialValue = analogRead(dialPin);
  dialState dial = getDialState(dialValue);

  dial = DIAL_MEDIUM; // Forced speed when dial disabled

  // -------- Wait until dial is not OFF --------
  while (dial == DIAL_OFF) {
    dialValue = analogRead(dialPin);
    dial = getDialState(dialValue);
  }

  Serial.println("Moving legs to start");

  // =====================================================
  // Phase 1: Smoothly move joints to start position
  // =====================================================
  for (int i = 1; i < 20; i++) {
    int leftKnee  = (LgaitIndex + offset) % GAIT_LENGTH;
    int rightKnee = (RgaitIndex + offset) % GAIT_LENGTH;

    sendMITCommand(-(R_hip[LgaitIndex] + 0.02f) * (i / 20.0f), v_des, kp, kd, -torque_ff_L_HIP * (i / 20.0f), MOTOR_ID_LEFT_HIP);
    delayMicroseconds(150); drainRXUntil(400);

    sendMITCommand(-(R_knee[leftKnee] * 0.8f) * (i / 20.0f), v_des, kp, kd, -torque_ff_L_KNEE * (i / 20.0f), MOTOR_ID_LEFT_KNEE);
    delayMicroseconds(150); drainRXUntil(400);

    sendMITCommand((R_hip[RgaitIndex] + 0.02f) * (i / 20.0f), v_des, kp, kd, torque_ff_R_HIP * (i / 20.0f), MOTOR_ID_RIGHT_HIP);
    delayMicroseconds(150); drainRXUntil(400);

    sendMITCommand((R_knee[rightKnee] * 0.8f) * (i / 20.0f), v_des, kp, kd, torque_ff_R_KNEE * (i / 20.0f), MOTOR_ID_RIGHT_KNEE);
    delayMicroseconds(200); drainRXUntil(500);

    delay(10);
  }

  // =====================================================
  // Phase 2: Continuous gait loop
  // =====================================================
  while (dial != DIAL_OFF) {

    int leftKnee  = (LgaitIndex + offset) % GAIT_LENGTH;
    int rightKnee = (RgaitIndex + offset) % GAIT_LENGTH;

    // (Dial override disabled for testing)
    dial = DIAL_MEDIUM;

    // Send real-time gait joint commands
    sendMITCommand(-(R_hip[LgaitIndex]) * 1.3, v_des, kp, kd, -torque_ff_L_HIP, MOTOR_ID_LEFT_HIP);
    sendMITCommand(-(R_knee[leftKnee] * .7) * 1.3, v_des, kp, kd, -torque_ff_L_KNEE, MOTOR_ID_LEFT_KNEE);
    sendMITCommand((R_hip[RgaitIndex]) * 1.3, v_des, kp, kd, torque_ff_R_HIP, MOTOR_ID_RIGHT_HIP);
    sendMITCommand((R_knee[rightKnee] * .7) * 1.3, v_des, kp, kd, torque_ff_R_KNEE, MOTOR_ID_RIGHT_KNEE);

    // Advance gait phase
    LgaitIndex = (LgaitIndex + 1) % GAIT_LENGTH;
    RgaitIndex = (RgaitIndex + 1) % GAIT_LENGTH;

    // Read and store feedback from motors
    while (mcp2515.readMessage(&canMsg) == MCP2515::ERROR_OK) {
      decodeMotorFeedback(&canMsg);
    }

    // Log data over Serial
    logGaitData(LgaitIndex, RgaitIndex);

    // Delay controls walking speed (dial adds delay)
    int _delay = 20 + dial;
    delay(_delay);
  }

  // Move legs back to zero position (neutral) after gait loop
Serial.println("Moving legs to zero");
for (int i = 1; i < 20; i++) {  // Gradually move back to the rest state in 20 small steps
    sendMITCommand(0, v_des, kp, kd, -torque_ff, MOTOR_ID_LEFT_HIP);
    sendMITCommand(0, v_des, kp, kd, -torque_ff, MOTOR_ID_LEFT_KNEE);
    sendMITCommand(0, v_des, kp, kd, torque_ff, MOTOR_ID_RIGHT_HIP);
    sendMITCommand(0, v_des, kp, kd, torque_ff, MOTOR_ID_RIGHT_KNEE);
    
    delay(50);  // Wait 50 ms between steps for smooth motion
}

delay(200);  // Extra delay to ensure all motors have reached zero
Serial.println("Finished moving legs to zero, restarting control loop");
}

// =========================================================
// Decode incoming CAN motor feedback
// =========================================================
void decodeMotorFeedback(struct can_frame *msg) {
  if (msg->can_dlc < 8) return;

  uint16_t motor_id = (uint16_t)(msg->can_id & 0xFF);

  if (motor_id == MOTOR_ID_RIGHT_HIP)       memcpy(msgDataRightHip,  msg->data, 8);
  else if (motor_id == MOTOR_ID_RIGHT_KNEE) memcpy(msgDataRightKnee, msg->data, 8);
  else if (motor_id == MOTOR_ID_LEFT_KNEE)  memcpy(msgDataLeftKnee,  msg->data, 8);
  else if (motor_id == MOTOR_ID_LEFT_HIP)   memcpy(msgDataLeftHip,   msg->data, 8);
}

// =========================================================
// Log gait data to Serial with timestamps
// =========================================================
void logGaitData(int LgaitIndex, int RgaitIndex) {

  if (gait_step_counter == 0) {
    Serial.println("TimeStep,Elapsed_us,L_Gait_Index,R_Gait_Index,RH[8],RK[8],LK[8],LH[8]");
  }

  // Reduce serial load (log every 5th step)
  if ((gait_step_counter % 5) != 0) { 
    gait_step_counter++; 
    return; 
  }

  int64_t elapsed_us = esp_timer_get_time() - t0_us;

  Serial.print(gait_step_counter); Serial.print(",");
  Serial.print((long long)elapsed_us); Serial.print(",");
  Serial.print(LgaitIndex); Serial.print(",");
  Serial.print(RgaitIndex); Serial.print(",");

  auto printRawData = [](uint8_t data[]) {
    for (int i = 0; i < 8; i++) {
      Serial.print(data[i]);
      if (i < 7) Serial.print(",");
    }
  };

  printRawData(msgDataRightHip);  Serial.print(",");
  printRawData(msgDataRightKnee); Serial.print(",");
  printRawData(msgDataLeftKnee);  Serial.print(",");
  printRawData(msgDataLeftHip);   Serial.println("");

  gait_step_counter++;
}

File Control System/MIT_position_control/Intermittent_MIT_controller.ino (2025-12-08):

// EASE Exoskeleton – MIT Position Control (Broadcast-friendly, with logging)
// Controls four lower-limb motors using prerecorded gait trajectories
// Logs CAN feedback with high-resolution ESP32 timestamps

#include <SPI.h>
#include <mcp2515.h>
#include <cstdint>
#include "esp_timer.h"          // ESP32 high-resolution timer

// CAN message structure
struct can_frame canMsg;
MCP2515 mcp2515(5);             // MCP2515 connected to SPI CS pin 5

const int dialPin = 34;         // Analog pin connected to potentiometer (speed dial)

// Potentiometer states
enum dialState {
  DIAL_OFF = -1,   // No motion
  DIAL_LOW = 40,   // Slow walking
  DIAL_MEDIUM = 20,// Normal walking
  DIAL_HIGH = 0    // Fast walking
};

// Track maximum amplitudes for logging (optional)
double maxAmp1 = 0, maxAmp2 = 0, maxAmp3 = 0, maxAmp4 = 0, total = 0, maxTotal = 0;

// Counter for logging gait steps
long gait_step_counter = 0;

// CAN feedback storage
uint8_t msgDataRightHip[8]  = {0};
uint8_t msgDataRightKnee[8] = {0};
uint8_t msgDataLeftHip[8]   = {0};
uint8_t msgDataLeftKnee[8]  = {0};

// Timer start for logging
int64_t t0_us = 0;              // Start timestamp in microseconds
float gaitTime = 0;

// Joint angles (for calculations)
double R_hip_ang = 0.0, R_knee_ang = 0.0, L_hip_ang = 0.0, L_knee_ang = 0.0;

// Number of samples per gait cycle
#define GAIT_LENGTH 100

// Pre-recorded gait trajectories for left and right legs
double L_knee[GAIT_LENGTH] = { /* 100 values for left knee trajectory */ };
double L_hip[GAIT_LENGTH]  = { /* 100 values for left hip trajectory */ };
double R_knee[GAIT_LENGTH] = { /* 100 values for right knee trajectory */ };
double R_hip[GAIT_LENGTH]  = { /* 100 values for right hip trajectory */ };

// Offset to adjust gait synchronization
int offset = 90;

// Last potentiometer reading (for smoothing)
int lastDialValue = 0;

// Unique motor IDs – update to match hardware
const uint8_t MOTOR_ID_LEFT_HIP  = 0x03;
const uint8_t MOTOR_ID_RIGHT_HIP = 0x01;
const uint8_t MOTOR_ID_LEFT_KNEE = 0x04;
const uint8_t MOTOR_ID_RIGHT_KNEE= 0x02;

// ---------- Helper Functions ----------

// Converts a float value to an unsigned integer for CAN message
static inline int float_to_uint(float x, float x_min, float x_max, unsigned int bits) {
  float span = x_max - x_min;
  if (x < x_min) x = x_min;
  if (x > x_max) x = x_max;
  return (int)((x - x_min) * ((float)((1u << bits) - 1u) / span));
}

// Drain CAN RX buffer for a short period to avoid overflow
// Stores the latest message by motor ID
static inline void drainRXUntil(uint32_t time_us) {
  const uint32_t t0 = micros();
  while (mcp2515.readMessage(&canMsg) == MCP2515::ERROR_OK) {
    uint8_t motor_id = (uint8_t)(canMsg.can_id & 0xFF); // Motor ID in low 8 bits
    if (motor_id == MOTOR_ID_RIGHT_HIP)       memcpy(msgDataRightHip,  canMsg.data, 8);
    else if (motor_id == MOTOR_ID_RIGHT_KNEE) memcpy(msgDataRightKnee, canMsg.data, 8);
    else if (motor_id == MOTOR_ID_LEFT_KNEE)  memcpy(msgDataLeftKnee,  canMsg.data, 8);
    else if (motor_id == MOTOR_ID_LEFT_HIP)   memcpy(msgDataLeftHip,   canMsg.data, 8);
    if ((micros() - t0) >= time_us) break;
  }
}

// Open all MCP2515 filters to accept any message
static inline void openAllFiltersAndRollover() {
  mcp2515.setFilterMask(MCP2515::MASK0, true, 0x00000000);
  mcp2515.setFilterMask(MCP2515::MASK1, true, 0x00000000);
  for (int i = 0; i <= 5; i++) mcp2515.setFilter((MCP2515::RXF0 + i), true, 0x00000000);
}

// Clamp float value within min and max
static inline float clampf(float x, float x_min, float x_max) {
  if (x < x_min) return x_min;
  if (x > x_max) return x_max;
  return x;
}

// Send current/brake command to motor
static inline void sendCurrentBrake(float i_brake_A, uint8_t motor_id) {
  float i_cmd = fabsf(i_brake_A);
  i_cmd = clampf(i_cmd, -60.0f, 60.0f);  // Clamp to datasheet limits

  int32_t i_scaled = (int32_t)(i_cmd * 1000.0f); // Scale to 0-60000

  uint8_t buf[4];
  buf[0] = (i_scaled >> 24) & 0xFF;
  buf[1] = (i_scaled >> 16) & 0xFF;
  buf[2] = (i_scaled >>  8) & 0xFF;
  buf[3] = (i_scaled)       & 0xFF;

  uint32_t can_id = motor_id | ((uint32_t)0x02 << 8); // Mode ID for current/brake

  canMsg.can_id  = can_id | CAN_EFF_FLAG;  
  canMsg.can_dlc = 4;

  memcpy(canMsg.data, buf, 4);
  mcp2515.sendMessage(&canMsg);
}

// Send MIT motor command (position, velocity, gains, feedforward torque)
static inline void sendMITCommand(float p_des, float v_des, float kp, float kd, float t_ff, uint8_t motor_id) {
  int p_int  = float_to_uint(p_des, -12.56f, 12.56f, 16);
  int v_int  = float_to_uint(v_des, -33.0f, 33.0f, 12);
  int kp_int = float_to_uint(kp, 0.0f, 500.0f, 12);
  int kd_int = float_to_uint(kd, 0.0f, 5.0f, 12);
  int t_int  = float_to_uint(t_ff, -54.0f, 54.0f, 12);

  uint32_t can_id = ((uint32_t)0x08 << 8) | motor_id; 
  canMsg.can_id  = 0x80000000UL | can_id; // Extended frame
  canMsg.can_dlc = 8;

  canMsg.data[0] = kp_int >> 4;
  canMsg.data[1] = ((kp_int & 0xF) << 4) | (kd_int >> 8);
  canMsg.data[2] = kd_int & 0xFF;
  canMsg.data[3] = p_int >> 8;
  canMsg.data[4] = p_int & 0xFF;
  canMsg.data[5] = v_int >> 4;
  canMsg.data[6] = ((v_int & 0xF) << 4) | (t_int >> 8);
  canMsg.data[7] = t_int & 0xFF;

  mcp2515.sendMessage(&canMsg);
}

// Setup ESP32 and MCP2515
void setup() {
  Serial.begin(921600);   // Fast serial for logging
  SPI.begin();

  mcp2515.reset();
  mcp2515.setBitrate(CAN_1000KBPS, MCP_8MHZ); // 1 Mbps CAN
  openAllFiltersAndRollover();
  mcp2515.setNormalMode();

  t0_us = esp_timer_get_time(); // Start timestamp
  delay(10000);                  // Optional delay to stabilize
  Serial.println("Multi-joint gait tracking started");
}

// Read dial and determine walking speed
dialState getDialState(int dialValue) {
  if (dialValue == 4095 && lastDialValue <= 4095 - 100) dialValue = lastDialValue;
  dialValue &= 0b1111111111100000;  // Smooth ADC noise
  lastDialValue = dialValue;

  int dialPercent = map(dialValue, 0, 4095, 0, 1000);
  if (dialPercent < 250) return DIAL_HIGH;
  if (dialPercent < 500) return DIAL_MEDIUM;
  if (dialPercent < 750) return DIAL_LOW;
  return DIAL_OFF;
}

// Decode feedback from motors
void decodeMotorFeedback(struct can_frame *msg) {
  if (msg->can_dlc < 8) return;
  uint16_t motor_id = (uint16_t)(msg->can_id & 0xFF); // Extract motor ID
  if (motor_id == MOTOR_ID_RIGHT_HIP)       memcpy(msgDataRightHip,  msg->data, 8);
  else if (motor_id == MOTOR_ID_RIGHT_KNEE) memcpy(msgDataRightKnee, msg->data, 8);
  else if (motor_id == MOTOR_ID_LEFT_KNEE)  memcpy(msgDataLeftKnee,  msg->data, 8);
  else if (motor_id == MOTOR_ID_LEFT_HIP)   memcpy(msgDataLeftHip,   msg->data, 8);
}
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

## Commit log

2025-09-23 Setup for main
    [Power Systems BOM.xlsx]
2025-11-12 adding graphs for experiments and fixed the issue of no updates from a only two CAN
    [gait_data_log_20251112_132415.csv, gait_data_log_20251112_132415_decoded.csv, gait_data_log_20251112_135753.csv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]
2025-11-12 added more tests and edited script to take elapsed_us instead of timesteps.
    [gait_data_log_20251112_141325.csv, gait_data_log_20251112_141325_decoded.csv, gait_data_log_20251112_144050.csv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]
2025-11-16 added stuff experiment 2
    [gait_data_log_20251114_161409.csv, gait_data_log_20251114_161409_decoded.csv, gait_data_log_20251114_163330.csv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]
2025-11-19 created new folders etc and done experiment 1 and 2 final
    [gait_data_log_20251111_173516.csv, gait_data_log_20251111_173516_decoded.csv, gait_data_log_20251111_173516_decoded_with_power.csv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]
2025-11-19 Conducted experiments up to experiment 4
    [gait_data_log_20251119_163952.csv, gait_data_log_20251119_165131.csv, owon_log_20251119_163952.csv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]
2025-11-20 finished all 8 experiments
    [gait_data_log_20251120_155146.csv, gait_data_log_20251120_160126.csv, gait_data_log_20251120_160636.csv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]
2025-11-21 added heaps of stuff and made graphs for the response variables
    [combined_output.csv, combined_output_decoded.csv, gait_data_log_20251119_160903_decoded.csv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]
2025-12-07 Comments for easier reading of motor control
    Updated the codebase to have comprehensive comments allowing future readability and use.
2025-12-07 Required MCP2515 file
    Added the required MCP2515 file requried to run the motors
2025-12-08 Implement leg return to zero position after gait
    Added functionality to move legs back to zero position after gait loop.
2025-12-08 Added CAD files for docking station
    [Docking Station Assembly.f3z, Vslot Corner Joint.f3d]
2025-12-08 Moved file
    [Docking Station Assembly.f3z]
2025-12-08 Added Corner joint CAD file
    [Vslot Corner Joint.f3d]
2025-12-08 Create Back and Arm rests folder
2025-12-08 Added front armrest CAD file
    [Armrest - Front section L and R.f3z]
